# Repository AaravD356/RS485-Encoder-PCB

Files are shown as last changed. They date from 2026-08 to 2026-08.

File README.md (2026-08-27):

# Arm-Encoder-PCB

RS485 encoder interface board for accurate joint position feedback on the **UMD Mars Rover Team's** autonomous arm. The board polls a multi-drop bus of RS485 absolute encoders and relays live position and velocity data over CAN to the rest of the rover's control system, with an STM32 handling the protocol translation.

## Overview

Each joint on the autonomous arm is fitted with an RS485 absolute encoder (AMT21x / AMT212 series). This board's STM32 firmware manages a bus of these encoders, round-robin polling each one, validating the returned data, and tracking position/velocity per node. That data is exposed over CAN so the arm's main controller can request live feedback for any specific joint on demand.

## Node Addressing

Each encoder on the bus is assigned a unique node ID, sent directly as the command byte for a standard position read:

Up to a configurable max number of encoders can be registered at once, each tracked independently with its own node ID, resolution, poll period, last-known position, and online/offline status. Four encoders are loaded by default at startup, but encoders can be added or cleared at runtime, with duplicate node IDs rejected.

## Bus Polling

The system round-robins through registered encoders rather than polling all of them every cycle, respecting each encoder's individual poll period. Each controller cycle:
1. Checks whether the current encoder's poll interval has elapsed.
2. If due, sends that encoder's node-addressed command and reads back the 2-byte response.
3. Validates the response using the AMT21 parity check (two check bits derived from the data payload).
4. Decodes the position from the response, scaled to the encoder's configured resolution (up to 14-bit).
5. Computes velocity from the position delta between reads, unwrapping across the resolution's modulo range to handle wraparound at the 0/max boundary.
6. Advances to the next encoder for the following cycle.

Encoders that fail to respond or fail checksum validation are marked offline, with failed/successful read counters tracked per node — this lets the system distinguish a genuinely disconnected encoder from an occasional dropped packet.

## RS485 Transport

Direction control (TX/RX switching) is handled either automatically by the UART hardware or manually via a GPIO-driven DE pin, depending on configuration. Before every transmission, the receive buffer is flushed to avoid stale data corrupting the next read. Transmit completion is polled with a timeout rather than assumed, so a bus fault or non-responding node can't hang the polling loop indefinitely.

## CAN Integration

The board exposes encoder data over CAN request/response:

- **Request** — the controller specifies a target encoder's node ID.
- **Response** — the board replies with that node's ID, position (in 0.1° units), and velocity (in 0.01°/s units), scaled from raw encoder counts based on the encoder's resolution.

Requests are matched to a registered encoder by node ID; if the encoder isn't found or isn't currently online, no meaningful data is returned. This request/response model means the main controller can poll specific joints on demand rather than needing to parse a continuous broadcast stream.

## Reliability Notes

- Per-node online/offline tracking rather than a single global "encoder ok" flag
- Failed reads don't stall the polling loop — the round-robin simply moves to the next node
- Position wraparound is explicitly handled in velocity calculation, avoiding large erroneous velocity spikes when an encoder crosses its zero point
- Duplicate node IDs are rejected at registration, preventing bus address collisions from being configured accidentally

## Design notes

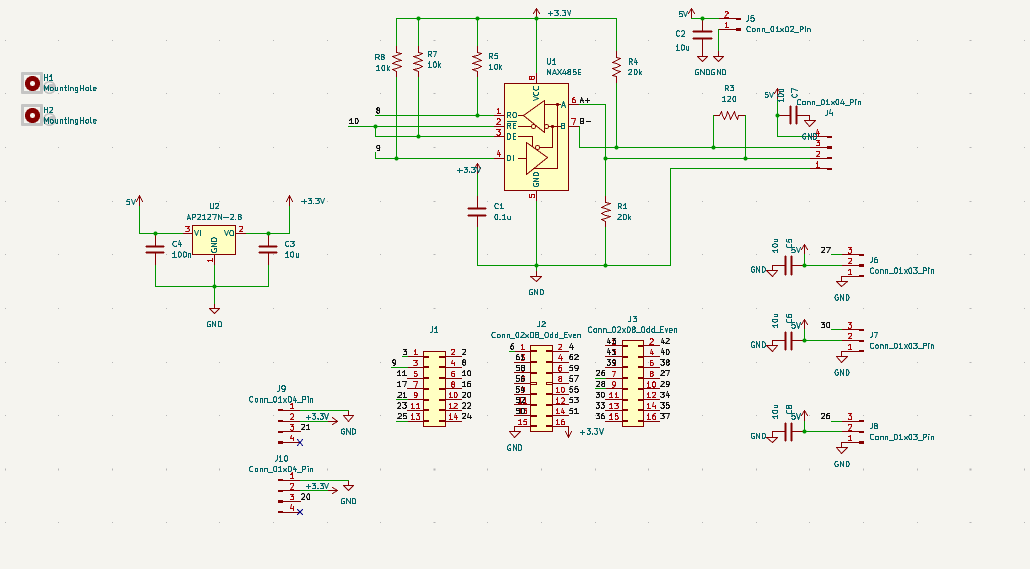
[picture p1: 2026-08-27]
Schematic.png

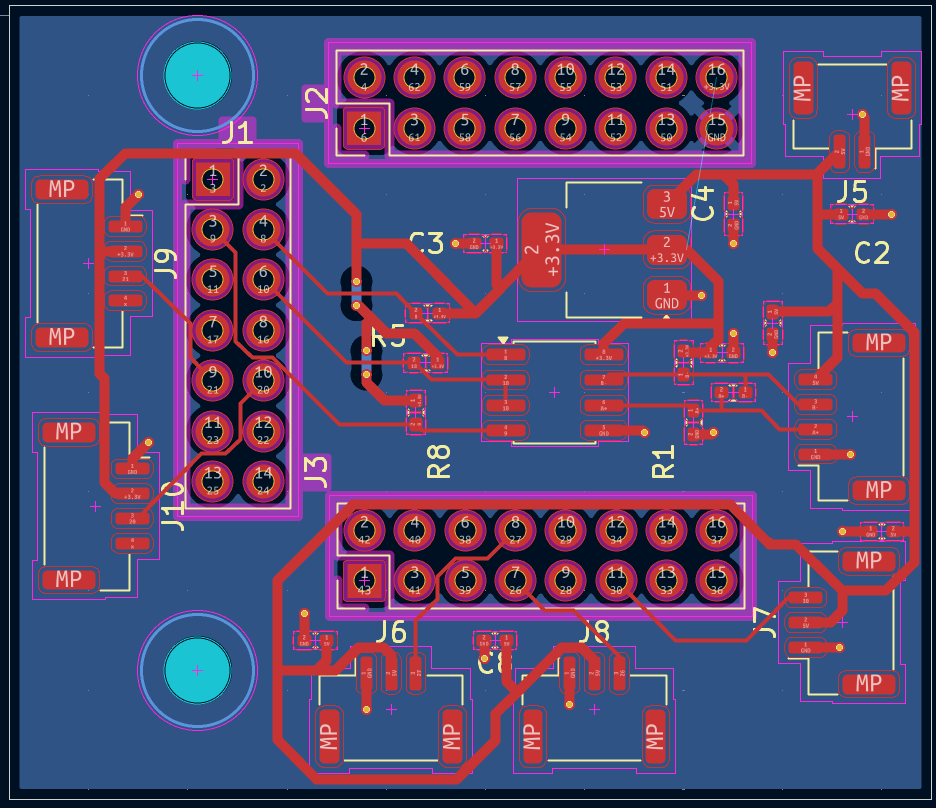
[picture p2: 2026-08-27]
Layout.png

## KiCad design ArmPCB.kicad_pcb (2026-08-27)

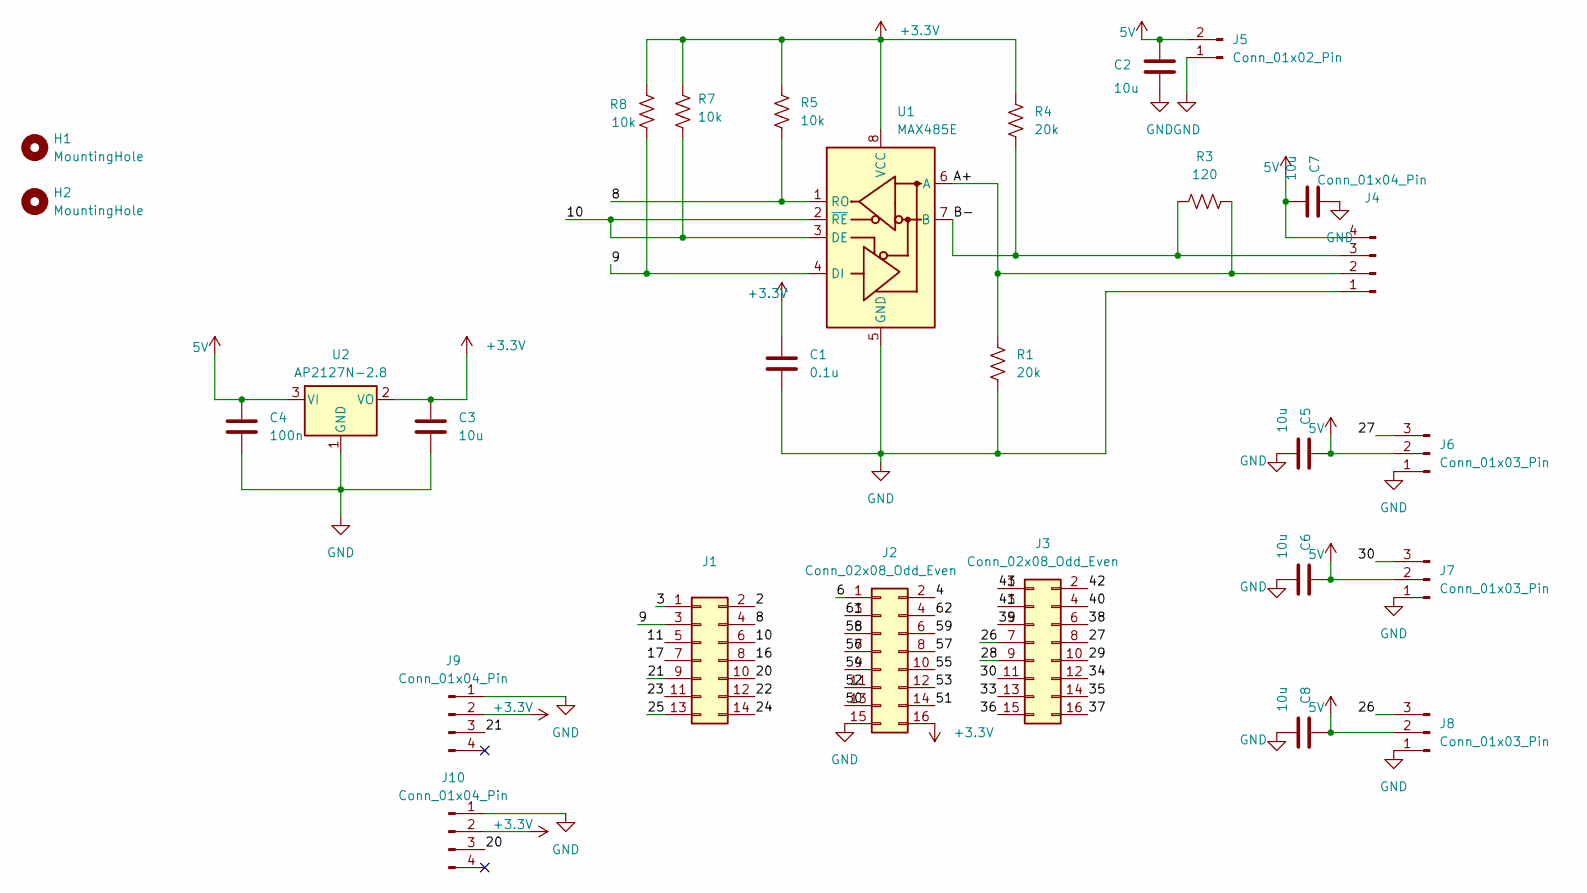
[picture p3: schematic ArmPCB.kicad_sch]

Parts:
C1: 0.1u; C_0402_1005Metric_Pad0.74x0.62mm_HandSolder
C2, C3, C5, C6, C7, C8: 10u; C_0402_1005Metric_Pad0.74x0.62mm_HandSolder
C4: 100n; C_0402_1005Metric_Pad0.74x0.62mm_HandSolder
H1, H2: MountingHole; MountingHole_3.2mm_M3_DIN965
J1: Conn_02x07_Odd_Even; PinHeader_2x07_P2.54mm_Vertical
J2, J3: Conn_02x08_Odd_Even; PinHeader_2x08_P2.54mm_Vertical
J4: Conn_01x04_Pin; JST_XH_S4B-XH-A_1x04_P2.50mm_Horizontal
J5: Conn_01x02_Pin; JST_XH_S2B-XH-A_1x02_P2.50mm_Horizontal
J6, J7, J8: Conn_01x03_Pin; JST_XH_S3B-XH-A_1x03_P2.50mm_Horizontal
J9, J10: Conn_01x04_Pin; JST_PH_S4B-PH-K_1x04_P2.00mm_Horizontal
R1, R4: 20k; R_0402_1005Metric_Pad0.72x0.64mm_HandSolder
R3: 120; R_0402_1005Metric_Pad0.72x0.64mm_HandSolder
R5, R7, R8: 10k; R_0402_1005Metric_Pad0.72x0.64mm_HandSolder
U1: MAX485E; SOIC-8_3.9x4.9mm_P1.27mm
U2: AP2127N-2.8; SOT-223-3_TabPin2

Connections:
5V: C2.1, C4.1, C5.1, C6.1, C7.2, C8.1, J4.4, J5.2, J6.2, J7.2, J8.2, U2.3 (VI)
+3.3V: C1.1, C3.1, J2.16, J9.2, J10.2, R4.2, R5.1, R7.1, R8.1, U1.8 (VCC), U2.2 (VO)
/2: J1.2
/3: J1.1
/4: J2.2
/6: J2.1
/8: J1.4, R5.2, U1.1 (RO)
/9: J1.3, R8.2, U1.4 (DI)
/10: J1.6, R7.2, U1.2 (~RE), U1.3 (DE)
/11: J1.5
/16: J1.8
/17: J1.7
/20: J1.10, J10.3
/21: J1.9, J9.3
/22: J1.12
/23: J1.11
/24: J1.14
/25: J1.13
/26: J3.7, J8.3
/27: J3.8, J6.3
/28: J3.9
/29: J3.10
/30: J3.11, J7.3
/33: J3.13
/34: J3.12
/35: J3.14
/36: J3.15
/37: J3.16
/38: J3.6
/39: J3.5
/40: J3.4
/41: J3.3
/42: J3.2
/43: J3.1
/50: J2.13
/51: J2.14
/52: J2.11
/53: J2.12
/54: J2.9
/55: J2.10
/56: J2.7
/57: J2.8
/58: J2.5
/59: J2.6
/61: J2.3
/62: J2.4
/A+: J4.2, R1.1, R3.2, U1.6 (A)
/B-: J4.3, R3.1, R4.1, U1.7 (B)
GND: C1.2, C2.2, C3.2, C4.2, C5.2, C6.2, C7.1, C8.2, J2.15, J4.1, J5.1, J6.1, J7.1, J8.1, J9.1, J10.1, R1.2, U1.5 (GND), U2.1 (GND)

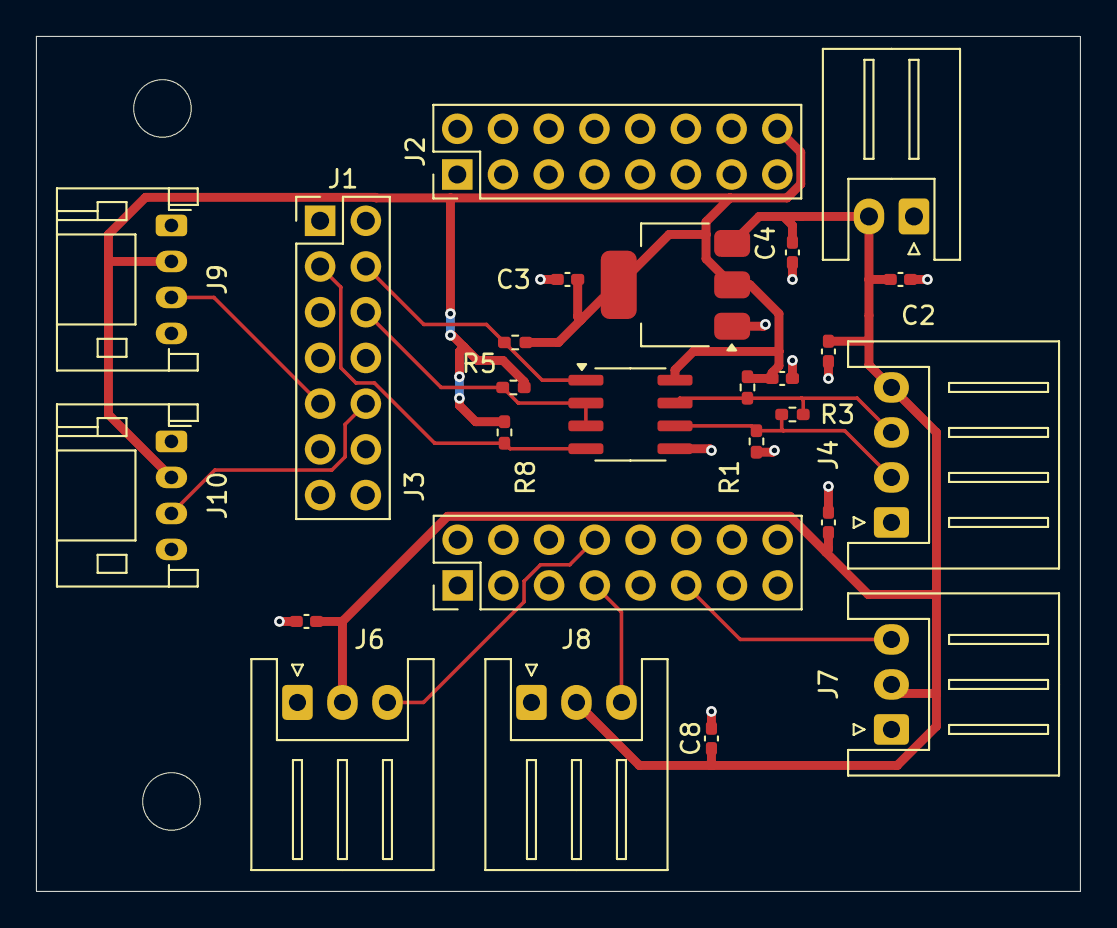
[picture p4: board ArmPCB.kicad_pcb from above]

Board: 2 copper layers, 58.0 x 47.5 mm, 28 parts (0 on the bottom side), 13 nets.
